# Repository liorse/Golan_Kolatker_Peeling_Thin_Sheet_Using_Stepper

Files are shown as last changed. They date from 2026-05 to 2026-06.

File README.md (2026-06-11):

# Peeling Thin Sheet Using Stepper Motor — ESP32 Controller

Firmware for an automated thin-sheet peeling machine driven by a NEMA 17 stepper motor and controlled via a Wemos D1 R32 (ESP32).

---

## Table of Contents

- [Overview](#overview)
- [Hardware](#hardware)
- [Wiring](#wiring)
- [Software Dependencies](#software-dependencies)
- [Installation](#installation)
- [Configuration](#configuration)
- [Serial Command Interface](#serial-command-interface)
- [Serial Output](#serial-output)
- [State Machine](#state-machine)

---

## Overview

This firmware:
- Controls a NEMA 17 stepper motor through a DM542T driver to drive a peeling stage.
- Drives a 240×320 ST7789 TFT display (landscape) with a live status UI and settings menu.
- Supports 4 physical buttons for UI navigation, start/stop, homing, and calibration.
- Reads two independent limit switches (home end and far end).
- Reads temperature via a MAX31856 thermocouple amplifier (K-type) and drives a heater MOSFET with a PID controller.
- Connects to an existing Wi-Fi network (station mode) and hosts a WebSocket-based status/control UI on port 80.
- Exposes a serial command interface (115 200 baud) for external software control via a USB-serial bridge.
- Emits a JSON heartbeat every 100 ms so a host application can monitor position, state, and temperature in real time.

---

## Hardware

| Component | Details |
|---|---|
| Microcontroller | Wemos D1 R32 (ESP32 dual-core, 240 MHz) |
| Stepper motor | NEMA 17 — rated 0.4 A |
| Stepper driver | DM542T (V4.0) — Leadshine digital driver, active-low ENA- |
| Display | 240×320 ST7789 TFT (VSPI, landscape rotation) |
| Limit switches | 2× microswitch — home end (X) and far end (Y) |
| Buttons | 4× push-button — A (start/stop), B (settings/home), X (increment/CAL), Y (decrement) |
| Thermocouple amplifier | Adafruit MAX31856 — K-type thermocouple, VSPI bus |
| Heater MOSFET | N-channel FET driven by 1 kHz PWM (LEDC) on GPIO 32 |

### Driver Configuration (DIP Switches)

| Switches | Function | Recommendation |
|---|---|---|
| SW1–SW3 | Peak output current | Match to motor rated current |
| SW4–SW6 | Microstep resolution | Match to firmware steps-per-rev setting (default 25600 steps/rev) |
| SW7 | Standby current reduction | ON = 50 % current at rest |
| SW8 | Pulse active edge | ON = rising edge (default) |

Refer to the DM542T datasheet for the exact SW1–SW3 current table.

---

## Wiring

### Stepper Driver

| ESP32 GPIO | Signal | Connected To |
|---|---|---|
| GPIO 26 | ENA+ | DM542T ENA+ (ENA- tied to GND) |
| GPIO 25 | DIR+ | DM542T DIR+ (DIR- tied to GND) |
| GPIO 27 | PUL+ | DM542T PUL+ (PUL- tied to GND) |

> The DM542T minimum HIGH is 3.5 V; ESP32 GPIO outputs 3.3 V — use a level shifter or voltage divider on step/dir/enable lines if the driver does not trigger reliably.

### Display (ST7789, VSPI)

| ESP32 GPIO | Signal |
|---|---|
| GPIO 18 | SPI SCK  (shared VSPI bus) |
| GPIO 23 | SPI MOSI (shared VSPI bus) |
| GPIO 19 | SPI MISO (shared VSPI bus) |
| GPIO  5 | TFT CS |
| GPIO 17 | TFT DC |
| GPIO  2 | TFT RST |
| GPIO 16 | TFT backlight |

### Thermocouple Amplifier (MAX31856, shares VSPI)

| ESP32 GPIO | Signal |
|---|---|
| GPIO 21 | MAX31856 CS |
| GPIO 22 | MAX31856 DRDY (data-ready, active-low) |

### Heater MOSFET

| ESP32 GPIO | Signal |
|---|---|
| GPIO 32 | Gate (1 kHz PWM via LEDC, 8-bit duty) |

### Buttons (active-low, internal pull-up)

| ESP32 GPIO | Button | Function |
|---|---|---|
| GPIO  4 | BTN_A | Start / stop; in settings: navigate up |
| GPIO 33 | BTN_B | Settings / home; in settings: navigate down / exit+save |
| GPIO 14 | BTN_X | In settings: increment (+) or trigger CAL |
| GPIO 12 | BTN_Y | In settings: decrement (−) |

### Limit Switches (active-low, internal pull-up)

| ESP32 GPIO | Switch | Triggers |
|---|---|---|
| GPIO 13 | Home / X end | HOMING → stop and zero position |
| GPIO 15 | Far / Y end  | CAL_RUNNING → record travel distance; PEELING/MOVING → safety abort |

---

## Software Dependencies

Install via the Arduino Library Manager before compiling:

| Library | Notes |
|---|---|
| **FastAccelStepper** | Hardware-timer step generation |
| **Adafruit ST7789** | TFT display driver |
| **Adafruit GFX** | Graphics primitives |
| **Adafruit MAX31856** | Thermocouple amplifier driver |
| **ESP Async WebServer** ≥ 3.3.x | Use the mathieucarbou fork — the me-no-dev fork has mbedtls API breakage with ESP32 core ≥ 3.x |
| **AsyncTCP** | Required by ESP Async WebServer |
| **ESPmDNS** | Bundled with the ESP32 core — no separate install needed |

---

## Installation

```bash
# Install ESP32 core (once)
arduino-cli core install esp32:esp32

# Compile
arduino-cli compile --fqbn esp32:esp32:d1_mini32 Peeling_Automation_Stepper_esp32/

# Upload (replace /dev/ttyUSB0 with the actual port)
# UploadSpeed=460800 is required — the CH340 on the D1 R32 drops at the default 921600
arduino-cli upload --fqbn esp32:esp32:d1_mini32:UploadSpeed=460800 --port /dev/ttyUSB0 Peeling_Automation_Stepper_esp32/

# Monitor serial output
arduino-cli monitor --port /dev/ttyUSB0 --config baudrate=115200
```

Add your Wi-Fi credentials in `Peeling_Automation_Stepper_esp32/wifi_credentials.h` before compiling.

### Serial Bridge (optional)

A Python serial bridge lets you control the instrument over USB without Wi-Fi:

```bash
cd serial_bridge
pip install -r requirements.txt
python serial_bridge.py          # auto-detect CH340
python serial_bridge.py /dev/ttyUSB0  # explicit port
```

Then open **http://localhost:8080** in any browser.

---

## Configuration

Key settings adjustable via the on-device settings menu (BTN_B → SETTINGS):

| Parameter | Description |
|---|---|
| Speed (µm/s) | Peel speed — adjustable at runtime via BTN_X/BTN_Y in settings |
| Angle (°) | Peeling arm half-angle θ — used for µm/step conversion |
| Start position (µm) | Distance from home to peel start point |
| CAL | Runs a full home→far-end traversal to measure travel distance |
| TEMP settings | PID setpoint, Kp/Ki/Kd, and controller on/off |
| Wait for temp | Hold peel at start position until temperature reaches setpoint |

Calibration (CAL) runs a full home→far-end traversal to measure travel distance automatically.

---

## Serial Command Interface

Connect at **115 200 baud**. Send a single character followed immediately by any numeric argument.

| Command | Argument | Description |
|---|---|---|
| `m` | `<int32>` | Move to absolute step position. Example: `m200000` |
| `s` | — | Stop motor immediately |
| `v` | `<int>` | Set motor max speed in Hz. Example: `v500` |
| `h` | `<0–255>` | Set heater duty cycle (blocked when PID control is active). Example: `h128` |
| `b` | `<A\|B\|X\|Y><1\|0>` | Virtual button press (1) or release (0). Example: `bA1` |

---

## Serial Output

Every **100 ms** the firmware emits a JSON heartbeat on Serial (and WebSocket). Key fields:

| Field | Description |
|---|---|
| `state` | State machine name: `"IDLE"`, `"MOVING"`, `"TO_START"`, `"WAIT_TEMP"`, `"PEELING"`, `"HOMING"`, `"SETTINGS"`, `"CAL_HOME"`, `"CAL_RUN"` |
| `position` | Current position in steps |
| `speed` | Current step rate (Hz) |
| `pos_um` | Current position in µm (peel distance) |
| `speed_um` | Current speed in µm/s |
| `speed_set` | Configured target speed in µm/s |
| `angle` | Configured arm half-angle (°) |
| `dist_xa_steps` | Calibrated X→A travel in steps (0 = not calibrated) |
| `dist_xa_um` | Calibrated X→A travel in µm |
| `peel_elapsed_ms` | Elapsed peel time in ms (non-zero during PEELING only) |
| `temp_c` | Thermocouple temperature in °C (`null` on fault) |
| `heater_duty` | Heater PWM duty 0–255 |
| `temp_setpoint` | Target temperature in °C |
| `temp_ctrl_active` | `true` when PID controller is running |
| `wait_for_temp` | `true` when peel waits for temperature to reach setpoint |
| `rssi` | Wi-Fi signal strength in dBm (0 = disconnected) |
| `clients` | Number of connected WebSocket clients |
| `ip` | Current Wi-Fi IP address string |

---

## State Machine

```
IDLE → [A, dist_xa > 0]           → MOVING_TO_START
IDLE → [A, dist_xa = 0]           → warning "RUN CAL FIRST" (stays IDLE)
IDLE → [B, pos = 0]               → SETTINGS
IDLE → [B, pos > 0]               → HOMING

MOVING_TO_START → [arrival + 100 ms, wait_for_temp = false] → PEELING
MOVING_TO_START → [arrival + 100 ms, wait_for_temp = true]  → WAITING_FOR_TEMP
WAITING_FOR_TEMP → [temp within ±2 °C of setpoint]          → PEELING

PEELING   → [motor reaches dist_xa or A or limit switch] → IDLE
HOMING    → [X limit switch]     → IDLE  (position := 0)
SETTINGS/CAL field → [X button]  → CAL_HOMING → CAL_RUNNING → IDLE (saves dist_xa)
Any moving state   → [A button]  → IDLE  (abort)

SETTINGS: A = navigate up, B = navigate down / exit+save, X = +/CAL/OPEN, Y = −
```

---

## Author

Lior Segev — Version 4.3.0-esp32, June 2026

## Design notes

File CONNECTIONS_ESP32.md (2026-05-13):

# ESP32 (Wemos D1 R32) — Wiring Reference

## Display — ST7789 via Pico Explorer Base header

The Pico Explorer Base display is permanently wired to the Pico's GPIO header.
Plug into those header pins directly; do **not** insert a Pico.

| Signal | ESP32 GPIO | Wemos D1 R32 label | Pico Explorer header pin | Pico GPIO |
|---|---:|---|:---:|---|
| DC | 17 | D4 | Pin 21 | GP16 |
| CS | 5 | D10 (SS) | Pin 22 | GP17 |
| SCK | 18 | D13 | Pin 24 | GP18 |
| MOSI | 23 | D11 | Pin 25 | GP19 |
| BL | 16 | D5 | Pin 26 | GP20 |
| GND | GND | GND | Pin 23 | GND |
| 3V3 | 3V3 | 3V3 | Pin 36 | 3V3\_OUT  |

> **RST** is not connected (firmware sets `TFT_RST = -1`). The display resets
> via the board's power-on rail.

> **Power**: with no Pico inserted, supply 3.3 V from the ESP32's 3V3 pin to
> Pico header **pin 36** to power the display circuitry.

---

## Buttons

All four Pico Explorer Base buttons are used. The X and Y buttons simulate the
home and far-end limit switches (microswitches) during bench testing.

| Function | ESP32 GPIO | Wemos D1 R32 label | Pico Explorer header pin | Pico GPIO |
|---|---:|---|:---:|---|
| BTN_A (start / stop / +) | 4 | A1 | Pin 16 | GP12 |
| BTN_B (settings / home / −) | 19 | D12 | Pin 17 | GP13 |
| BTN_X (home limit / simulate)  | 14 | IO14 | Pin 19 | GP14 |
| BTN_Y (far limit / simulate) | 12 | IO12 | Pin 20 | GP15 |

> All buttons are active-low. The ESP32 enables internal pull-ups so no
> external resistor is needed.

> **GPIO 21 (SDA) and GPIO 22 (SCL) are now free** for I2C peripherals.

> GPIO 12 is a strapping pin but safe to use here: the WROOM module's internal
> pull-down holds it LOW during reset (correct flash voltage), and the firmware's
> `INPUT_PULLUP` takes over after boot.

---

## Stepper Driver (DM542T)

| Signal | ESP32 GPIO | Wemos D1 R32 label | DM542T terminal |
|---|---|---|---|
| ENA+ | 26 | D2 | ENA+ |
| DIR+ | 25 | D3 | DIR+ |
| PUL+ | 27 | D6 | PUL+ |
| GND | GND | GND | ENA− / DIR− / PUL− (all three) |

> Active-high wiring: the − terminals are tied to GND, and the MCU drives the
> + terminals. ENA+ must go HIGH ≥ 200 ms before the first pulse (firmware
> uses 500 ms).

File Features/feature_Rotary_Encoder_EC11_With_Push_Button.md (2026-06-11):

# Feature: Rotary Encoder EC11 With Push Button

## Hardware
- **Component**: 360° Rotary Encoder EC11 with push button — bare 5-pin metal component (no breakout board)
- **Pin layout**:

```
3-pin side (encoder):        2-pin side (push button):
  [CLK]  [GND]  [DT]              [SW]  [SW]
    1      2      3                 4     5
```

- **Wiring**:
  - Pin 1 (CLK) → GPIO 14 (was BTN_X)
  - Pin 2 (middle/common) → GND
  - Pin 3 (DT) → GPIO 4 (was BTN_A)
  - Pin 4 or 5 (SW) → GPIO 33 (was BTN_B)
  - Pin 4 or 5 (SW, other) → GND
  - GPIO 12 (was BTN_Y) — left unused
  - **VCC not needed** — ESP32 INPUT_PULLUP provides pull-up; encoder shorts CLK/DT to GND

- **Identify pins**: use a multimeter in continuity mode — pressing the shaft should beep across the 2-pin side (push button). The 3-pin row is always the encoder.

## Compile-time switch

```cpp
#define ROTARY  1
#define BUTTONS 2
#define INPUT_MODE  ROTARY   // change to BUTTONS for 4-button mode
```

Place at the top of the `.ino` file. Comment/change `INPUT_MODE` to switch modes. No other code changes needed.

## Behaviour

### Main screen (IDLE)
- Rotate CW / CCW → move cyan highlight between **GO** and **SET/HOME** buttons (wraps)
- Push (SW) → activates the highlighted button
- Virtual buttons (WiFi / serial bridge) → bypass encoder, trigger actions directly (unchanged)

### Settings screen
- Button boxes are drawn **empty** (no labels) in rotary mode
- Two navigation modes:

  **Browse mode** (default on entry):
  - Rotate CW / CCW → move cyan highlight between settings fields (circular wrap)
  - Fields in order: SPEED → ANGLE → START → CAL → TEMP → WAIT_TEMP → EXIT
  - Push on a numeric field → enter **Edit mode**
  - Push on **CAL** → triggers calibration immediately (no edit mode)
  - Push on **WAIT_TEMP** → toggles value immediately (no edit mode)
  - Push on **EXIT** → saves settings and returns to main screen

  **Edit mode** (entered by pushing on a numeric field):
  - Rotate CW → increment value (1 click = 1 button-press step, same as existing X button)
  - Rotate CCW → decrement value (same as existing Y button)
  - Push → confirm value, return to Browse mode

### Temp sub-menu
Follows the exact same pattern as main settings:
- Browse mode: rotate between fields, push to enter edit or trigger action
- Fields: BACK (direct exit), SETPOINT, KP, KI, KD (all edit mode), STARTSTOP (direct toggle)

### Focus reset
Focus always resets to the **first field / button** (index 0) on every screen transition.

## Visual indicator
Focused button / field gets a **cyan background** with black text — distinct from idle (black bg) and pressed (white border) states.

## Encoder reading
- Polled in `loop()` — no interrupts
- **Software debounce**: ignore CLK transitions faster than 5 ms
- SW push button: existing 500 ms press/release logic, no long-press action

## What does NOT change
- The TFT display layout
- The WiFi web UI
- The serial bridge UI
- Virtual button protocol (`bA1`/`bA0` etc.)
- All existing logic when `INPUT_MODE BUTTONS` is selected

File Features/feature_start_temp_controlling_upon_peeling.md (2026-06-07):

# Feature: wait_for_temp — Start Peeling When Temperature is Reached

## Summary

Add a `wait_for_temp` yes/no setting. When enabled, pressing GO moves the motor to the
start position and then holds in a new `WAITING_FOR_TEMP` state until the thermocouple
reads within ±2 °C of the setpoint before starting the peel stroke.

## Agreed Design Decisions

| # | Question | Decision |
|---|---|---|
| 1 | Auto-activate temp control on GO? | No — user controls it manually; GO only auto-enables if `wait_for_temp=YES` and control is OFF |
| 2 | `wait_for_temp=YES` but `tempControlActive=OFF`? | Auto-enable temp control (reset PID), set `tempCtrlAutoEnabled=true`, proceed |
| 3 | Timeout if temp never arrives? | None — A-button abort works as today |
| 4 | State machine | New `WAITING_FOR_TEMP` state between `MOVING_TO_START` and `PEELING` |
| 5 | "Reached" threshold | ±2 °C — reuses existing `stable` definition |
| 6 | Settings placement | Top-level field after `FIELD_TEMP`: `SPEED → ANGLE → START → CAL → TEMP → WAIT_TEMP → [exit+save]` |
| 7 | UI during wait | State label = `"WAIT TEMP"` (yellow); right-column temp bar already shows progress |
| 8 | On peel end | Auto-disable heater only if `tempCtrlAutoEnabled`; leave on if user enabled it manually |

## Implementation Checklist

- [x] `AppState` enum: add `WAITING_FOR_TEMP`
- [x] `SettingsField` enum: add `FIELD_WAIT_TEMP`
- [x] New globals: `bool waitForTemp`, `bool tempCtrlAutoEnabled`
- [x] `cycleSettingsField()`: insert `FIELD_WAIT_TEMP` before exit
- [x] Button handler `SETTINGS`: `X=YES`, `Y=NO` for `FIELD_WAIT_TEMP`
- [x] `startMoveToStart()`: if `waitForTemp && !tempControlActive` → auto-enable PID + set flag
- [x] `MOVING_TO_START` case: on motor stop, go to `WAITING_FOR_TEMP` instead of calling `startPeeling()`
- [x] New `WAITING_FOR_TEMP` case: check ±2 °C → call `startPeeling()`
- [x] `abortAndIdle()` + `PEELING → IDLE`: if `tempCtrlAutoEnabled`, turn heater off + clear flag
- [x] EEPROM: bump magic `PEL5 → PEL6`, add `waitForTemp` field
- [x] Settings display: render `FIELD_WAIT_TEMP` row as `"WAIT:YES"` / `"WAIT:NO"`
- [x] Heartbeat JSON: add `"wait_for_temp"` bool field
- [x] Web UI (PROGMEM + `serial_bridge/index.html`): add `WAIT_TEMP` to `STATE_COL` (yellow), render state label

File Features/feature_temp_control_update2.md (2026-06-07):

# Temperature Control Implementation

## PID Parameters (from analysis)

```
KP = 60.0
KI = 0.15
KD = 900.0
PID_BAND = 4.0°C   # Bang-bang outside, PID inside
```

## Control Algorithm

```python
def compute_heater_pwm(current_temp, setpoint, dt):
    error = setpoint - current_temp

    # 1. Safety cutoffs (skip PID entirely)
    if isnan(current_temp) or current_temp >= 120.0:
        return 0.0

    # 2. Bang-Bang outside active zone
    if error > PID_BAND:
        return 100.0   # Full power for fast warmup
    if error < -PID_BAND:
        return 0.0     # Turn off if over-temperature

    # 3. PID within the zone
    P_term = KP * error

    integral_stored += error * dt
    integral_stored = clamp(integral_stored, -50/KI, +50/KI)  # I-term contribution ±50%
    I_term = KI * integral_stored

    raw_derivative = (error - last_error) / dt
    filtered_derivative = 0.7 * filtered_derivative + 0.3 * raw_derivative  # low-pass
    D_term = KD * filtered_derivative

    last_error = error
    output = P_term + I_term + D_term
    return clamp(output, 0.0, 100.0)
```

## Design Decisions

| # | Decision |
|---|---|
| 1 | PID runs inside the temp-read `if` block, right after `lastTempC` is set, using `dt = (nowMs - lastPidRunMs) / 1000.0f` |
| 2 | PID writes `heaterDuty` directly (0–255); `h` serial command is blocked with log when `tempControlActive == true` |
| 3 | `integral_stored`, `last_error`, `filteredDerivative` reset to 0 only on false→true activation |
| 4 | Heater zeroed immediately on true→false deactivation |
| 5 | `isnan(lastTempC)` → force off; `lastTempC >= 120.0°C` → force off; both skip PID |
| 6 | I-term clamped to ±50 (integral_stored clamped to `±50/ki`) |
| 7 | Derivative low-pass filtered: `filteredDerivative = 0.7f * prev + 0.3f * raw` |
| 8 | `tempControlActive` always boots `false` regardless of EEPROM |
| 9 | First tick after activation skips computation, just records `lastPidRunMs` |

## New State Variables

```cpp
float         pidIntegral        = 0.0f;
float         pidLastError        = 0.0f;
float         pidFilteredDeriv    = 0.0f;
unsigned long lastPidRunMs        = 0;
```

All reset to 0 on activation; `lastPidRunMs = 0` triggers first-tick skip.

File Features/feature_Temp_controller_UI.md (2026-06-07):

# Temperature Controller UI

## Resolved Design (grilling session 2026-06-07)

---

## Layout

- Canvas expands to **320×240** — the physical ST7789 display is already 320 wide; the firmware previously used only the centre 240 px.
- **Left column** (x 0–199, 200 px): existing stepper UI — run screen and settings screen, content unchanged except minor horizontal squeeze.
- **Right column** (x 200–319, 120 px): temperature bar, visible on **both** Run and Settings screens at all times.
- Vertical cyan divider separates the two columns.
- The existing `T: xx.x C` text row is **removed** from the left column (replaced by the right-column bar).

---

## Right Column — Temperature Bar

Top to bottom:

1. **Status indicator** (y ≈ 4)
   - `CTRL:OFF` in gray — loop not running
   - `CTRL: ON` blinking yellow at 500 ms — loop active, not yet stable
   - `STABLE` solid green — loop active and within ±2 °C of setpoint
2. **Power %** (y ≈ 18) — `PWR: xx%` (heater_duty / 255 × 100), cyan
3. **Vertical thermometer bar** (y 46–220, height 174 px)
   - Fills **bottom-to-top** (0 °C at bottom, 120 °C at top)
   - **Red** fill when not stable, **green** fill when stable
   - On fault (`temp_c = null`): entire bar red, shows `FLT`
4. **Setpoint line** — white horizontal line across the bar at the setpoint temperature, **always visible** regardless of control state
5. **Current temperature label** — floats to the right of the bar, near the top of the filled portion (`xx.x` format)

---

## Settings Screen

Main settings gains a 5th entry: **TEMP SETTINGS** (press `+`/`OPEN` to enter sub-menu).

### TEMP sub-menu fields (6 entries, navigated with A=up / B=down)

| # | Field | X button | Y button |
|---|---|---|---|
| 0 | `< BACK` | `BACK` — exits sub-menu | no-op |
| 1 | Setpoint | `+` / increment | `−` / decrement |
| 2 | Kp | `+` | `−` |
| 3 | Ki | `+` | `−` |
| 4 | Kd | `+` | `−` |
| 5 | Start/Stop | `ON` — enable control | `OFF` — disable control |

Pressing B on the last field (Start/Stop) exits the sub-menu back to main settings on the TEMP entry.

---

## Defaults, Ranges, and Steps

| Parameter | Default | Range | Step |
|---|---|---|---|
| Setpoint | 50 °C | 0–120 °C | 1 °C |
| Kp | 60 | 0–200 | 1 |
| Ki | 0.15 | 0–2.0 | 0.01 |
| Kd | 900 | 0–2000 | 10 |

PID rationale: slow thermal system with large thermal mass. Kp=60 avoids slamming. Ki=0.15 (Ti ≈ 400 s) is patient. Kd=900 (Td ≈ 15 s) applies early braking to prevent overshoot.

**Stability threshold**: ±2 °C (matches the planned bang-bang hysteresis; also tolerates MAX31856 noise floor).

---

## Firmware Additions (this step — control loop deferred)

| Item | Detail |
|---|---|
| New variables | `float tempSetpoint`, `bool tempControlActive`, `float kp`, `float ki`, `float kd` |
| EEPROM | Added to `SavedSettings`; magic bumped to `"PEL5"` |
| JSON heartbeat | `temp_setpoint`, `temp_ctrl_active`, `kp`, `ki`, `kd`, `in_temp_sub`, `temp_field` |
| Control loop | **Deferred to next step** |

---

## What is NOT in this step

- PID control loop execution (no output calculation, no integral/derivative accumulation)
- Automatic heater PWM from the loop (heater still driven by `h<duty>` serial command or manual override)

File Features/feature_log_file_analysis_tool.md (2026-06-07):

# Log File Analysis Tool

## Goal

A standalone HTML/JS tool for analysing peeling experiment CSV log files.

## Data Source

Log files are at `/home/liors/.config/peeling-controller/logs/`.

Two CSV schemas exist (tool handles both):
- **Older:** `timestamp, time_ms, pos_um, speed_um_s, temp_c, state`
- **Newer:** `timestamp, time_ms, pos_um, speed_um_s, temp_c, heater_duty, state`

## Design Decisions

| # | Decision | Choice |
|---|---|---|
| 1 | X-axis | Wall-clock timestamp (`timestamp` column) |
| 2 | Multi-file display | One chart, all selected runs overlaid with distinct colors |
| 3 | Duty cycle display | Text label in legend per run — e.g. "Run 14:10 — duty 255 (100%)" |
| 4 | File selection | Folder picker → checklist of CSVs to include |
| 5 | Chart library | Chart.js from CDN |
| 6 | Output location | `analysis_folder/analysis.html` |

## Behaviour

- User clicks "Open Folder", picks the logs folder
- A checklist of all `.csv` files appears (sorted newest-first)
- User checks the runs they want and clicks "Plot"
- A single temperature-vs-time chart renders with one colored line per run
- Each legend entry shows: filename stem + duty cycle if available (e.g. "14:10 — duty 100%")
- Files missing `heater_duty` show "duty n/a" in the legend

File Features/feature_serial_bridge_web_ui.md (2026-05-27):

# Feature: Serial-Bridge Web UI

## Request

Serve the same web UI that is currently served by the ESP32 over WiFi, but this time the
communication channel is the USB serial port.  The user runs a Python program on their
computer which:

1. Connects to the ESP32 over serial (USB/UART).
2. Serves the same webpage on `http://localhost:8080`.
3. Lets the user control the instrument through the identical web UI.

Parallel operation must be preserved: WiFi WebSocket and serial bridge can be active at the
same time.  Physical buttons + TFT display continue to function normally.

---

## Design Decisions (resolved)

| # | Topic | Decision |
|---|---|---|
| 1 | ESP32 firmware change | Add `bA1`/`bA0` serial commands for virtual button press/release injection.  Format: `b` + letter (`A`/`B`/`X`/`Y`) + `1` (press) or `0` (release).  Parsed with two `Serial.read()` calls after the `b` command character.  Keeps the entire state machine (settings, homing, CAL) in the firmware — full parity with WiFi mode. |
| 2 | Python stack | `asyncio` + `websockets` + `pyserial`.  Single Python file.  Two pip packages beyond stdlib. |
| 3 | Serial port selection | Auto-detect CH340 USB-serial adapter by VID `1A86` / PID `7523`.  If multiple CH340 ports are found, pick the first and print the full list as info.  User can override with a CLI positional argument: `python serial_bridge.py /dev/ttyUSB1`. |
| 4 | File layout | `serial_bridge/serial_bridge.py` + `serial_bridge/requirements.txt`. |
| 5 | HTTP / WS port | 8080 (default).  Can be overridden with a CLI argument. |
| 6 | HTML source of truth | `serial_bridge/index.html` — one canonical copy. |
| 7 | ESP32 HTML serving | Keep PROGMEM string in the sketch (reverted from LittleFS).  HTML is stored as `static const char HTML_PAGE[] PROGMEM = R"rawhtml(...)rawhtml"` in the `.ino` file.  Served via `req->send_P(200, "text/html", HTML_PAGE)`.  Python bridge reads `serial_bridge/index.html` directly from disk.  Both copies must be kept in sync when editing the UI. |
| 8 | LittleFS upload method | ~~Not needed — reverted to PROGMEM.~~  No separate filesystem flash step required. |
| 9 | Serial disconnection | Auto-reconnect.  Bridge polls for the CH340 port every 2 s.  Browser status line shows "SERIAL — reconnecting…" during the gap. |
| 10 | Button command format | `bA1` / `bA0` — three ASCII bytes.  `b` = button-inject command, next byte = button letter (`A`/`B`/`X`/`Y`), next byte = `1` (press) or `0` (release). |
| 11 | Transport indicator | Python injects `"transport":"serial"` into every JSON heartbeat it relays to the browser.  The shared `index.html` JavaScript checks for this field and shows a 🔌 SERIAL badge in the status line.  WiFi path is completely unchanged (field absent → badge hidden). |
| 12 | Listen address | `127.0.0.1` (localhost only).  Not exposed to the LAN by default. |
| 13 | Multi-CH340 behaviour | Pick the first found; print all detected ports as informational output.  User specifies a port explicitly via CLI arg to override. |

---

## Data Flow

```
ESP32 serial TX  →  Python asyncio reader  →  inject "transport":"serial"  →  ws.send(json)  →  browser
browser click    →  ws.recv({"btn":"A","action":"press"})  →  serial.write("bA1")  →  ESP32 onButtonPress()
```

The 100 ms JSON heartbeat that the firmware already emits on `Serial` is the sole state source;
the Python bridge passes it through verbatim (plus the injected `transport` field).

---

## Files to Create / Modify

| File | Action |
|---|---|
| `serial_bridge/serial_bridge.py` | **Create** — asyncio bridge |
| `serial_bridge/requirements.txt` | **Create** — `websockets`, `pyserial` |
| `serial_bridge/index.html` | **Create** — extracted from PROGMEM + SERIAL badge JS |
| ~~`Peeling_Automation_Stepper_esp32/data/index.html`~~ | ~~symlink to serial_bridge/index.html~~ — not needed (PROGMEM approach) |
| `Peeling_Automation_Stepper_esp32/Peeling_Automation_Stepper_esp32.ino` | **Modify** — (a) add `b` command to serial parser, (b) embed HTML as `PROGMEM` raw-string `HTML_PAGE`, served via `req->send_P()` |
| ~~`tools/upload_fs.py`~~ | ~~mklittlefs + esptool.py wrapper~~ — not needed (PROGMEM approach) |
| `CLAUDE.md` | **Update** — serial bridge usage; note about keeping PROGMEM + serial_bridge/index.html in sync |

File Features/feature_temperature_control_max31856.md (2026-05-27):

# Temperature Control — Future Feature

A future firmware update will add closed-loop temperature control of a heat pad.

## Hardware

- **Sensor**: CJMCU MAX31856 thermocouple amplifier with K-type thermocouple (SPI interface)
- **Actuator**: N-channel MOSFET module controlled via PWM (resistive heat pad load)

---

## Pin Conflict Resolution

GPIO 19 is currently `BTN_B` in firmware but is also declared as the VSPI MISO pin in
`SPI.begin(18, 19, 23, -1)`. The ST7789 display is write-only so this conflict was
harmless — until now. Wiring MAX31856 SDO to GPIO 19 would cause the sensor to fight the
button pull-up on every SPI read.

**Fix**: move BTN_B from GPIO 19 → GPIO 33 (one firmware line, one rewired breadboard wire).
GPIO 19 becomes a clean MISO. `SPI.begin()` is unchanged.

```cpp
// Peeling_Automation_Stepper_esp32.ino
#define BTN_B   33   // was 19
```

---

## MAX31856 Wiring

| MAX31856 Pin | Purpose | Connect to | Notes |
|---|---|---|---|
| VIN | Power input | ESP32 **3.3 V**  | Breakout has onboard regulator |
| 3Vo | Regulated 3.3 V output | **NC** | Output from breakout — leave unconnected |
| GND | Ground | **GND** | |
| SCK | SPI clock | **GPIO 18** | Shared VSPI SCK (display uses it too) |
| SDI | SPI data in (MOSI) | **GPIO 23** | Shared VSPI MOSI |
| SDO | SPI data out (MISO) | **GPIO 19** | Clean MISO now that BTN_B has moved |
| CS | Chip select (active-low) | **GPIO 21** | |
| DRDY | Data-ready interrupt | **GPIO 22** | New conversion ready ≈ every 143 ms |
| FLT | Fault output | **NC** | Read fault register via SPI instead |

---

## MOSFET PWM Wiring

| Signal | GPIO | Notes |
|---|---|---|
| PWM → MOSFET gate | **GPIO 32** | ESP32 LEDC, **1 kHz**, 8-bit duty |

---

## BTN_B Change Summary

| Signal | Old GPIO | New GPIO |
|---|---|---|
| BTN_B  | 19 | **33** |

---

## Remaining Free GPIOs After This Addition

| GPIO | Type | Status |
|---|---|---|
| 34 | Input-only  | Spare  |
| 35 | Input-only  | Spare  |
| 39 | Input-only  | Spare  |

---

## Future Firmware Implementation Notes

When implementing the temperature control loop:

1. **Library**: `Adafruit_MAX31856` — declare with `cs=21, drdy=22`
2. **PWM setup**:
   ```cpp
   ledcSetup(channel, 1000, 8);      // 1 kHz, 8-bit
   ledcAttachPin(32, channel);
   ledcWrite(channel, duty);          // 0–255
   ```
3. **EEPROM**: add `float target_temp_c` to `SavedSettings`; bump `EEPROM_MAGIC` to `"PEL5"`
4. **Settings field**: add `FIELD_TEMP` after `FIELD_CAL` in the `SettingsField` enum
5. **Safety**: on any MAX31856 fault (open/short thermocouple), immediately set PWM duty = 0
6. **Control**: start with bang-bang (on/off at setpoint ± hysteresis); upgrade to PID later if needed

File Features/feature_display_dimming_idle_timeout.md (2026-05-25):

# Display Dimming — Feature Spec

## Request
Dim the display after 20 seconds of idle activity (no external button pressed, no WiFi/WebSocket command received). Light it back up if a button is pressed or a WiFi command is sent.
Dim to 20% brightness.

## Decisions

| # | Question | Decision |
|---|---|---|
| 1 | Wake-on-press behaviour | **Wake + act** — the button press both restores brightness and executes its action (no double-press required) |
| 2 | Motor running = idle? | **Dim even during motor movement** — active PEELING/HOMING/MOVING states do not reset the timer |
| 3 | Serial commands | **Yes** — serial `m`, `s`, `v` commands reset the idle timer and wake the display |
| 4 | Timeout configurable? | **Hardcoded** `#define DIM_TIMEOUT_MS 20000` — not added to the Settings screen |
| 5 | Transition style | **Gradual fade** 255 → 51 over 1 second (linear, every loop iteration) |
| 6 | Wake transition | **Instant snap** to full brightness — no fade-up |

## Implementation Notes
- Brightness controlled via ESP32 LEDC PWM on GPIO 16 (TFT_BL), core 3.x pin-based API (`ledcAttach` / `ledcWrite`)
- `BL_FULL = 255`, `BL_DIM = 51` (20% of 255)
- Activity sources: physical buttons, WebSocket messages (via `wsActivityFlag` volatile bool), serial commands
- `wakeDisplay()` helper: snaps to full brightness + resets `lastActivityMs`
- Dim state machine: `displayFading` → linear interpolation → `displayDimmed`

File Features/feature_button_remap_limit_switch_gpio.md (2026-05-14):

# Corrections 9 — Button Remapping & Limit Switch GPIO

## Changes implemented

### New pin assignments
- `BTN_X` (GPIO 14) — now a UI button: **+** in settings, triggers CAL on CAL field, no-op outside settings
- `BTN_Y` (GPIO 12) — now a UI button: **−** in settings, no-op outside settings
- `LIMIT_SW` (GPIO 13) — **new**: both limit switches wired in parallel to this single pin (active-low, INPUT_PULLUP). Will be split to GPIO 32 and GPIO 33 in a future revision.

### Settings menu button mapping (new)

| Button | Action |
|---|---|
| A | Navigate **up** through fields (no-op on first field: SPEED) |
| B (short press) | Navigate **down**; exits and saves when leaving the last field (CAL) |
| X (press / hold) | **+** increment with auto-repeat; on CAL field → triggers calibration run |
| Y (press / hold) | **−** decrement with auto-repeat; no-op on CAL field |

### Outside settings
- X and Y are **no-ops** in all non-settings states.
- A and B behaviour in IDLE / moving states is unchanged.

### Display
- TFT button labels in settings: A=`UP`, B=`DOWN`, X=`+`/`CAL`, Y=`-`
- Hint line (`tap=NEXT  hold=-`) **removed** from both TFT and web UI.
- Web UI button labels are dynamic: show `+`/`-` in settings, `X`/`Y` otherwise.

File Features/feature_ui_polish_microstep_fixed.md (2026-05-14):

# Corrections 10 — UI Polish & Microstep Simplification

## Changes implemented

### 1. X and Y buttons hidden on main screen
- Outside the settings menu, the X and Y button boxes are erased (filled solid black, no border).
- They only appear when in settings, showing `+` / `CAL` and `-`.

### 2. UP / DOWN button font size
- In the settings menu, the A (`UP`) and B (`DOWN`) button labels now use text size 2, matching the size of `GO`, `STOP`, and `SET`/`HOME` on the main screen.

### 3. Microstep setting removed from UI; value fixed at 25600
- `FIELD_STEPS` removed from the `SettingsField` enum.
- Settings navigation is now: **Speed → Angle → Start → CAL → exit+save**.
- `steps_per_rev` is a compile-time constant (`25600`). It is no longer stored in or loaded from EEPROM.
- EEPROM magic bumped from `PEL3` → `PEL4`; existing saved settings are cleared on first boot. **Calibration must be re-run after flashing.**
- Settings field Y-positions spread slightly (24 px spacing instead of 22 px) now that there are only 4 rows.
- Web UI updated to match: 4-field loop, `settings_field===3` is CAL, X/Y boxes blank outside settings.

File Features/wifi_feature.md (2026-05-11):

# WiFi Feature — Design Specification

## Goal
Connect to the instrument via WiFi and get a browser UI that:
1. Pixel-perfectly replicates the physical 240×240 ST7789 display
2. Updates in real-time as the physical display changes
3. Exposes all four buttons (A, B, X, Y) as remotely actuatable controls

---

## Design Decisions

### WiFi Mode
- **Station mode** — ESP32 joins `WIS_Hotspot` (open network, no password)
- Credentials stored in `wifi_credentials.h` (gitignored), not hardcoded in `.ino`
- Boot is **non-blocking**: if the hotspot is unavailable the instrument works normally as a physical device
- Settings screen shows `"WiFi: connecting…"`, `"WiFi: 192.168.x.y"`, or `"WiFi: offline"` in real time
- mDNS advertises `http://peeling.local` for a permanent bookmark

### Real-Time Protocol
- **WebSocket** — ESP32 pushes a JSON heartbeat to all connected clients every 100 ms
- Library: `ESPAsyncWebServer` + `AsyncTCP`

### Browser UI
- **Pixel-perfect HTML canvas**, 240×240 internal coordinates, **CSS-scaled** to fit the viewport
- Both the **run screen and settings screen** are mirrored exactly
- No browser-only controls — strict mirror of the physical UI
- Canvas click/touch events on button regions send press/release WebSocket commands

### Button Semantics
- All four buttons (A, B, X, Y) are remotely actuatable
- **Press + Release events** — browser sends `{"btn":"A","action":"press"}` on mousedown/touchstart and `{"btn":"A","action":"release"}` on mouseup/touchend
- X and Y function as **limit switch simulators** — identical behavior to the physical microswitches
- Firmware injects virtual button state via `volatile bool virtualBtn[4]`, ORed with `digitalRead()` in the loop

### Concurrency
- `AsyncWebServer`/`AsyncTCP` run on core 0; `loop()` runs on core 1
- Shared variables protected with `portENTER_CRITICAL` / `portEXIT_CRITICAL` spinlock
- WebSocket callbacks write only to the virtual button booleans and a broadcast-pending flag; `loop()` owns all state machine logic

### Heartbeat Expansion
The 100 ms heartbeat JSON is expanded from ~70 bytes to ~200 bytes to support full canvas rendering:

```json
{
  "state": "PEELING",
  "position": 12345,
  "speed": 100,
  "pos_um": 11.58,
  "speed_um": 15.20,
  "speed_set": 15.0,
  "angle": 30,
  "spr": 1600,
  "dist_xa_steps": 478085,
  "dist_xa_um": 448.2,
  "start_pos_um": 0.0,
  "peel_elapsed_ms": 3200,
  "warning_active": false,
  "settings_field": 0,
  "btn": [false, false, false, false],
  "ip": "192.168.1.47"
}
```

### HTML Delivery
- Entire page (HTML + CSS + JS) stored as an **inline PROGMEM string** in the `.ino`
- No separate filesystem upload step required — same `arduino-cli compile/upload` as today

### IP Display
- IP address shown in the **settings screen** on the TFT (below the cal status line)
- Also accessible via mDNS at `http://peeling.local`

---

## Required Libraries
Install via Arduino Library Manager:
- `ESPAsyncWebServer` (by me-no-dev or mathieucarbou fork)
- `AsyncTCP` (by me-no-dev)
- `ESPmDNS` (built into ESP32 core — no install needed)

---

## Known Limitations
- If two browsers are open simultaneously, both can send button events. The firmware processes them in arrival order — no inter-client locking. Acceptable for single-lab use.
- The `enableMotor()` call blocks `loop()` for 500 ms (hardware DM542T requirement). During this window heartbeats are delayed; the browser will show a brief stale state. Harmless in practice.

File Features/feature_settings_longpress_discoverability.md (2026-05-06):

In the UI, when I press set the lower button shows the text next and the upper button shows in the specific situation + and in the cal option cal. all is fine. But, I want to alert the user that he can also press a long press on the lower button to function as a - and not just a next for a short press.

IMPLEMENTED: Two-pronged discoverability fix for the B button long-press decrement in Settings:

1. Button label — the lower-left button (B) now shows "NEXT/-" (textSize 1) instead of "NEXT" (textSize 2), communicating both the short-press (NEXT) and long-press (-) actions directly on the button.

2. Hint line — "tap=NEXT  hold=-" is drawn at y=56 (between the "SETTINGS" title and the first field) in cyan at textSize 1. It disappears when the CAL field is active (where long-press B has no effect) and reappears on any other field.

Implementation: `drawButtonBox` gained an optional `sz` parameter (default 2) for textSize. `updateButtons` passes `bSz=1` and label `"NEXT/-"` for the B button in SETTINGS. A new `drawSettingsHint(fieldIdx)` helper draws or clears the hint line; called from `updateSettingsContent` on first draw and on every field change.

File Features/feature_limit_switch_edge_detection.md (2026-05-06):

there is a problem with the limit switches.

the problems description is as follow:

when the instrument returns home and the home limit switch is turned on. it remains turned until the motor moves out of home. but the motor can't move because it is on. 

the solution is to detect a rising or a falling edge, whatever is needed and not query the current limit switch position.

FIXED: replaced level-detection with falling-edge + 2 ms debounce for the safety abort
in MOVING / MOVING_TO_START / PEELING states. The fix applies symmetrically to both the
home (X) and far-end (Y) limit switches.

Implementation: `limitXPrev`/`limitYPrev` track the switch state from the previous loop
iteration; `limitXStableAt`/`limitYStableAt` record the timestamp of the falling edge.
The abort fires only when the switch has been continuously LOW for ≥ 2 ms AND was HIGH
on the preceding iteration (`xNewPress` / `yNewPress` flags). Once fired the timer is
cleared so the abort does not re-trigger for the same press.

HOMING and CAL_HOMING states retain level-detection (no change): those states are only
entered when the motor is away from the home switch, so a LOW reading always means a
fresh contact.

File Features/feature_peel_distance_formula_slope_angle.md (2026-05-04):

I finally have the formula for the real distance travelled upon one pulse for one step for the stepper motor.

real_distance_travelled = 2 * (distance travelled in one step) * cos( slope angle/2)

slope angle is given deg. this is the angle the user inputs in the settins menu.

calculate speed and distance according to this formula

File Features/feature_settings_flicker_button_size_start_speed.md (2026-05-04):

1. when going in to setting and trying to change values the display flickers. can you fix that?
   FIXED: replaced full-area fillRect+redraw with targeted per-row updates. Only the active
   field row is redrawn on value changes; only the old and new rows update on field transitions.
   Title and cal status are drawn once on entry.

2. buttons text are too small. can you make them as large as POS text for example
   FIXED: BTN_W widened 28→52 px; drawButtonBox switched to textSize 2 (12×16 px per char)
   with corrected centering math.

3. when going to start please use the same speed as you do for homing the device.
   FIXED: startMoveToStart() now uses CAL_SPEED_HZ (1067 Hz ≈ 1 mm/s) instead of 100 Hz.

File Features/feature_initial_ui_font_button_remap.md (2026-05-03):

in the main screen the fonts are too small. make them as large as the font in POS:0.0

there is a mix up with the buttons. make buttons X and Y the microswitch button simulations. they cannot take part in the UI manipulation.

The calibration should be run in a relative high speed 5mm/sec is acceptable.

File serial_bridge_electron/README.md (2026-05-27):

# Peeling Controller — Electron App

Node.js / Electron port of `serial_bridge.py`.  
Double-click the app → serial bridge starts → window opens automatically.

## Development

**Requires Node ≥ 16** (use nvm if your system node is older):

```bash
# If you have nvm:
nvm use 17      # or any ≥ 16

npm install
npm start                         # open app window
npm start -- /dev/ttyUSB0        # specify serial port (Linux)
npm start -- COM3                 # specify serial port (Windows)
```

The first `npm install` runs `electron-rebuild` automatically to compile
`serialport`'s native bindings against the bundled Electron Node version.

## Bridge-only (no Electron window)

```bash
node bridge.js                    # auto-detect CH340
node bridge.js /dev/ttyUSB0      # explicit port
node bridge.js --http-port 9090  # custom HTTP port
```

Then open **http://localhost:8080** in any browser — same as the Python bridge.

## Build distributable

```bash
npm run dist:linux   # → dist/  (.AppImage + .deb, x64)
npm run dist:win     # → dist/  (.exe installer + portable, x64)
```

**Cross-compilation note**: `serialport` uses native C++ bindings.  
To build the Windows `.exe` you must run `npm run dist:win` **on Windows**.  
To build the Linux `.AppImage` run `npm run dist:linux` **on Linux**.

Experiment logs (CSV) are written to:
- **Development**: `serial_bridge_electron/logs/`
- **Packaged app**: `%APPDATA%\peeling-controller\logs\` (Windows)  
  or `~/.config/peeling-controller/logs/` (Linux)

## How it differs from the Python bridge

| | Python bridge | Electron app |
|---|---|---|
| Runtime needed | Python 3.8 + pip | none (self-contained) |
| Opens browser | manually | automatic window |
| Log location | `serial_bridge/logs/` | user data dir (packaged) |
| Platforms | any with Python | Windows, Linux |

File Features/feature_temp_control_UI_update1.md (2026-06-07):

# Temperature Column UI Update 1

## Original Problems

1. Flickering in the temp part of the display
2. Residual lines when changing setpoint
3. Setpoint line flickering
4. Bar too small; requested bigger and centered
5. Show setpoint temperature above the setpoint line
6. Make temp area as small as possible (more room for peeling window)
7. Fonts in the temp column too small

## Design Decisions (resolved via grilling)

### Flicker fix (items 1, 3)
**Decision:** dirty-state tracking — `updateTempColumn()` now stores `prevFillH`,
`prevSpY`, `prevBarColor`, `prevHeaterDuty`, `prevCtrlStatus`, `prevTempDrawn`,
`prevTempLabelY`, and `prevFault` as static locals. Each section only repaints
pixels when the relevant value changes.

### Residual setpoint lines (item 2)
**Decision:** track `prevSpY`. On setpoint change: erase old line at full width
(`TBAR_X - 4`, length `TBAR_W + 8` — includes the 4 px overhang that caused the
ghost lines), clear the entire label column (`fillRect` from `labelX` to screen
right), then redraw the new line and label. Force bar redraw to restore any fill
pixels overwritten by the erase.

### Bar size and position (item 4)
**Decision:** `TBAR_W` widened from 22 → 40 px. `TBAR_X` shifted from 205 → 209
to center the bar+label block within the 119 px right column
(margin = (119 − 103) / 2 = 8 px; 103 = 40 bar + 3 gap + 60 label).

### Item 6 — column width
**Decision:** keep floating temp label to the right of the bar (user preference).
Column width unchanged at 119 px. The wider bar (40 px) plus size-2 label
consumes 103 px, leaving 8 px margin each side — visually centered.

### Setpoint label (item 5)
**Decision:** show setpoint value (e.g. `"50C"`) in size-2 to the right of the
bar at `y = spY − 17` (one text-row above the setpoint line), clamped to
`[TBAR_TOP, TBAR_BOT − 16]`.

### Temp label vs setpoint label collision
When temperature approaches setpoint the two labels would overlap. Resolution:
if `|tempLabelY − spY| < 12`, push the temp label to `spY + 2` (just below the
setpoint line). Both labels remain visible; setpoint label stays above the line.

### Fonts (item 7)
**Decision:** `setTextSize(2)` for all right-column text (status, PWR%, temp
label, setpoint label). All text fits within the 119 px column at size-2.

## Files Changed

- `Peeling_Automation_Stepper_esp32/Peeling_Automation_Stepper_esp32.ino`
  - `#define TBAR_X 209` (was 205)
  - `#define TBAR_W  40` (was 22)
  - `updateTempColumn()` fully rewritten with dirty-state tracking
  - JS constants in PROGMEM string updated: `TBAR_X=209,TBAR_W=40`
- `serial_bridge/index.html`
  - JS constants updated: `TBAR_X=209,TBAR_W=40`

---

## Follow-up Session — Bug Fixes & Layout Polish

### Bug: Black screen after exiting settings

**Root cause:** `updateRunContent()` uses static `prev*` variables to skip unchanged
rows. When B navigates from FIELD_TEMP back to IDLE, `clearContent()` wipes the left
panel, but all statics still matched the old IDLE values → every `strcmp`/`!=` check
passed and nothing was redrawn.

**Fix:** Added global `bool runScreenDirty = false;`. In the 100 ms heartbeat, when
the screen transitions settings → run, set `runScreenDirty = true`. At the top of
`updateRunContent()`, if the flag is set, reset all statics to their sentinel values
and clear the flag — forcing a full redraw in the same tick.

### Bug: Flicker and erasure of vertical divider during run screen

**Root cause:** Two rows overflowed past `LEFT_W = 200 px` into the right temperature
column on every heartbeat tick:

| Row | Start x | Chars × 12 px | End x | Overflow |
|-----|---|---|---|---|
| State label | 0 | 20 × 12 = 240 | 240 | 40 px |
| POS / warning | 6 | 19 × 12 = 228 | 234 | 34 px |

The overflow overwrote the vertical divider line and portions of the temperature bar.
Because `updateTempColumn()` uses dirty-state tracking (not a full redraw), the damage
persisted until the next partial repaint, causing visible flicker and ghosting.

**Fix:**
- State label reduced to **16 chars** centred in the left column
  (`16 × 12 = 192 px` from x = `(200 − 192) / 2 = 4`; ends at x = 196).
- POS normal row: `"um      "` (8 chars) → `"um   "` (5 chars);
  total 4 + 7 + 5 = 16 chars from x = 6; ends at x = 198.
- POS warning row: `"!CAL FIRST!        "` (19 chars) → `"!CAL FIRST!     "` (16 chars);
  from x = 6, ends at x = 198.
- `prevSb` buffer shrunk from 22 → 18 bytes to match.

### Layout: Centred state label

The 16-char state string is now drawn starting at x = 4 (formula:
`(LEFT_W − 16 × 12) / 2 = 4`) instead of x = 0. Both firmware and JS updated.

### Layout: Centred WiFi icon and client count

**Problem:** WiFi icon was at `cx = 120`, client count at x = 136. With 2-digit counts
the text reached x = 148, overlapping the top-right button box (x = 145..197).

**Decision:** Move icon to `cx = 100` — the geometric centre of the 90 px gap between
the two top button boxes (left button ends at x = 55, right button starts at x = 145;
centre = (55 + 145) / 2 = 100).

| Element | Old | New |
|---|-----|-----|
| WiFi icon centre | cx = 120 | cx = 100 |
| Icon span | x = 106..134 | x = 86..114 |
| Client count x | 136 | 116 |
| Client count max (2 digits) | 148 (clips button) | 128 (clear of button at 145) |

Both firmware (`drawWifiIcon()` + heartbeat client-count draw) and JS updated.

## All Files Changed (cumulative)

- `Peeling_Automation_Stepper_esp32/Peeling_Automation_Stepper_esp32.ino`
  - `#define TBAR_X 209`, `#define TBAR_W 40`
  - `updateTempColumn()` — dirty-state tracking
  - `updateRunContent()` — `runScreenDirty` reset, 16-char state label at x=4,
    shortened POS/warning rows, `prevSb[18]`
  - `drawWifiIcon()` — `cx = 100`
  - Heartbeat client-count draw — `fillRect(114,...)`, `setCursor(116,...)`
  - Global `bool runScreenDirty`
  - JS in PROGMEM — `cx=100`, client count at x=116, state label 16 chars at x=4,
    POS/warning rows shortened to 16 chars
- `serial_bridge/index.html` — same JS changes as PROGMEM copy
- `serial_bridge_electron/index.html` — same JS changes (WiFi icon cx=100,
  client count at x=116, state label 16 chars at x=4, POS/warning rows shortened)

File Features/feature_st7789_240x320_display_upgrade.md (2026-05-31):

## New 2.8" 240×320 ST7789 display — decisions

**Goal:** swap in the 2.8" 240×320 RGB display (same ST7789 interface), rotate it CW 90°, and fix the inverted colors.

### Decisions

| Question | Decision |
|---|---|
| Orientation after rotation | Landscape (320 wide × 240 tall) |
| Connector edge in landscape | Right edge → `setRotation(3)` |
| Layout changes | None for now; content stays in left 240×240 region |
| Panel offset | No offset — start with `tft.init(240, 320)` and check |

### Color inversion explanation

The ST7789 chip has a display-inversion register (INVON/INVOFF). Different panel manufacturers ship with it in different states. The old 240×240 module had it off; the new 240×320 module has it on, causing black↔white swap. Fix: `tft.invertDisplay(false)` after `tft.init()` — the Adafruit ST7789 `init()` already calls `invertDisplay(true)` internally, so we override it with `false`.

### Code changes (setup())

```cpp
// Before
tft.init(240, 240);
tft.setRotation(2);

// After
tft.init(240, 320);
tft.setRotation(3);
tft.invertDisplay(false);
```

### Future work
- Extend layout to use the full 320px width (extra 80px currently blank on the right).

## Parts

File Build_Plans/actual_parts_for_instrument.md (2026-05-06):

# Peeling Instrument — Build Specification

## Original Requirements
this is an interesting option for a display:
https://www.adafruit.com/product/3787

also a good option:
https://www.adafruit.com/product/4311

1. A professional-looking box containing the power supply, Pico W (WiFi), and stepper driver.
2. Box inputs: power button (24V rail + 5V Pico), two UI buttons, USB connector for firmware updates, 220V socket.
3. Box outputs: stepper motor connector, display.
4. Minimal soldering.
5. Power the Pico from the 24V DC rail (no battery).

---

## Decisions Made

| Topic | Decision |
|---|---|
| MCU | Raspberry Pi Pico W (RP2040 + WiFi) — NOT Pico 2W |
| Pico power | TSR 1-2450 buck regulator (24V → 5V, SIP-3), feeds VSYS pin |
| Pico programming | Panel-mount micro-USB on rear; coexists with VSYS power (internal OR-diode) |
| WiFi | Status monitoring + remote control (firmware TBD separately) |
| Enclosure | Hammond 1455Q2202 — 220×125×52mm aluminum body, plastic end panels (RF-transparent for Pico W WiFi) |
| AC switching | Illuminated rocker switch on front panel (mains-rated, 250V/10A) |
| IEC inlet | Rear panel, IEC C14 + integrated fuse holder, 1A T slow-blow fuse |
| Display | Waveshare Pico-ResTouch-LCD-3.5 (ILI9488, 480×320, ~73×49mm active area) — plugs directly onto Pico 40-pin header via SPI1 (GP8–GP13, GP16–GP17); **firmware pin reassignment + driver change required (not yet done)** |
| UI buttons | 2× Gateron KS-33 LP Brown (tactile) + low-profile MX keycaps, 14×14mm plate cutout, snap into 1.5mm aluminum panel |
| Button illumination | State-controlled via GPIO 0 (B-LED) and GPIO 1 (Y-LED) through 2N2222 transistors (reassigned from GP6/7 which conflict with Waveshare) |
| AC switching | Rear panel — illuminated rocker switch (mains-rated, 250V/10A); moved from front panel to accommodate 3.5" display width |
| Stepper output | GX16-4 aviation connector, 4-pin, female panel-mount on rear |
| Motor cable end | GX16-4 male plug (A+/A−/B+/B−) |
| Labels | Front Panel Express custom-printed aluminum panel |
| Display bezel | 3D-printed (design after ST7789 module arrives and PCB is measured) |
| E-stop | None |

---

## Complete Parts List

### Enclosure
| Part | MPN | Spec | Source | ~Cost |
|---|---|---|---|---|
| [Hammond 1455Q2202](https://www.hammfg.com/part/1455Q2202) | 1455Q2202 | 220×125×52mm, plastic end panels (WiFi-transparent) | [Mouser](https://www.mouser.com/ProductDetail/Hammond-Manufacturing/1455Q2202?qs=CUcEH/sN5tIHhQeXecWocA%3D%3D) / [DigiKey](https://www.digikey.com/en/products/detail/hammond-manufacturing/1455Q2202/2094863) | ~$35 |

### Power
| Part | MPN | Spec | Source | ~Cost |
|---|---|---|---|---|
| [Mean Well LRS-75-24](https://www.meanwell.com/productPdf.aspx?i=403) | LRS-75-24 | 24V / 3.2A, 75W | (already owned) — [DigiKey](https://www.digikey.com/en/products/detail/mean-well-usa-inc/LRS-75-24/7705055) / [Amazon](https://www.amazon.com/MeanWell-LRS-75-24-Power-Supply-75W/dp/B077B3X7S3) | — |
| [TSR 1-2450](https://www.tracopower.com/model/tsr-1-2450) | TSR 1-2450 | 24V → 5V / 1A, SIP-3 | [Mouser](https://www.mouser.com/ProductDetail/TRACO-Power/TSR-1-2450?qs=ckJk83FOD0XFKqda0Mzkgw%3D%3D) / [DigiKey](https://www.digikey.ca/en/products/detail/traco-power/TSR-1-2450/9383780) | $6 |
| [Schurter 4301.1400](https://www.schurter.com/en/products-and-solutions/components/connectors/power-entry-modules) | 4301.1400 | IEC C14 + fuse holder, panel-mount | [Mouser](https://www.mouser.com/c/connectors/power-entry-connectors/?m=Schurter) | $5 |
| Fuse T1A 5×20mm | — | 1A slow-blow | Any (DigiKey, Mouser, Amazon) | $1 |

### Front Panel
| Part | MPN | Spec | Source | ~Cost |
|---|---|---|---|---|
| [KCD3 rocker switch](https://www.aliexpress.com/w/wholesale-kcd3-rocker-switch.html) | KCD3 | 22×30mm cutout, 250V/10A, illuminated | [AliExpress](https://www.aliexpress.com/w/wholesale-kcd3-rocker-switch.html) | $3 |
| [Waveshare Pico-ResTouch-LCD-3.5](https://www.waveshare.com/pico-restouch-lcd-3.5.htm) | Pico-ResTouch-LCD-3.5 | ILI9488, 480×320, ~73×49mm active area, plug-on Pico board (SPI1 GP8–GP13, GP16–GP17) | [Waveshare](https://www.waveshare.com/pico-restouch-lcd-3.5.htm) | ~$25 |
| [Gateron KS-33 LP 2.0 Brown (35pcs)](https://www.gateron.com/products/gateron-ks-33-low-profile-switch-set) | KS-33 Brown | Low-profile tactile, 14×14mm plate cutout, SMD LED slot, 1.5mm plate snap-in | [Gateron](https://www.gateron.com/products/gateron-ks-33-low-profile-switch-set) / [Amazon](https://www.amazon.com/GATERON-Switches-Pre-lubed-Mechanical-Keyboard/dp/B0BZYHJ9XB) | ~$15 (35pcs, need 2) |
| Low-profile MX keycaps 1U blank (×2) | — (generic) | LP MX stem, fits KS-33 — e.g. Nuphy or Keychron LP caps | [Amazon](https://www.amazon.com/s?k=low+profile+mx+keycap+1u+blank) / [Keychron](https://www.keychron.com) | ~$5 |
| [Front Panel Express panel](https://www.frontpanelexpress.com/) | — (custom) | 122×78mm, **1.5mm aluminum** (required for MX snap-in mount) | [frontpanelexpress.com](https://www.frontpanelexpress.com/) | ~$40 |

### Rear Panel
| Part | MPN | Spec | Source | ~Cost |
|---|---|---|---|---|
| [GX16-4 female panel-mount](https://www.aliexpress.com/item/32830722292.html) | GX16-4 | 4-pin aviation socket | [AliExpress](https://www.aliexpress.com/item/32830722292.html) | $2 |
| [GX16-4 male cable-end](https://www.aliexpress.com/item/32830722292.html) | GX16-4 | 4-pin aviation plug (for motor cable) | [AliExpress](https://www.aliexpress.com/item/32830722292.html) | $2 |
| [Panel-mount micro-USB](https://www.aliexpress.com/w/wholesale-micro-usb-panel-mount.html) | — (generic) | Female, solder terminals | [AliExpress](https://www.aliexpress.com/w/wholesale-micro-usb-panel-mount.html) | $4 |

### MCU
| Part | MPN | Spec | Source | ~Cost |
|---|---|---|---|---|
| [Raspberry Pi Pico W](https://www.raspberrypi.com/products/raspberry-pi-pico/) | SC0918 | RP2040, 2.4GHz WiFi, micro-USB | [Raspberry Pi](https://www.raspberrypi.com/products/raspberry-pi-pico/) / [Adafruit](https://www.adafruit.com/product/5526) / [DigiKey](https://www.digikey.com/en/products/detail/raspberry-pi/SC0918/16608263) | $6 |

### Internal Electronics
| Part | MPN | Qty | Source | ~Cost |
|---|---|---|---|---|
| 2N2222 NPN transistor (TO-92) | 2N2222A | 2 | Any | <$1 |
| 1kΩ resistor 1/4W | — (generic) | 2 | Any | <$1 |
| Perfboard strip | — (generic) | 1 small | Any | $1 |

### Wiring & Connectors
| Item | Notes |
|---|---|
| 1.5mm² mains wire (L/N/PE) | Brown, blue, green-yellow — IEC inlet → rocker switch → PSU |
| Bootlace ferrules 1.5mm² | Crimp on all mains wire ends |
| 0.5mm² hookup wire, assorted | DC signals and LED wiring |
| Dupont female-to-female cables 20cm | Pico GPIO → display (7 wires) and GPIO → buttons |
| Short micro-B to micro-B USB cable | Internal: panel-mount USB socket → Pico W USB port |

---

## Front Panel Layout (122mm × 78mm)

```
|←13→|←14→|←8→|←────73────→|←14→|
      BTN-B       DISPLAY
      BTN-Y
```

PWR rocker is on the rear panel (3.5" display fills available front width).
All items vertically centered on the 78mm face.

---

## Internal Wiring Summary (minimal soldering)

| Connection | Method | Solder joints |
|---|---|---|
| 220V inlet → front rocker → PSU | Ferrule-crimped wire | 0 |
| PSU 24V → DM542T power | Screw terminals both ends | 0 |
| DM542T step/dir/ena → Pico GPIO | DM542T screw terminals + Dupont on Pico header | 0 |
| PSU 24V → TSR 1-2450 → Pico VSYS | Short wires, SIP-3 on perfboard | ~3 |
| Pico GPIO → display | Dupont female-to-female harness (7 wires) | 0 |
| Pico GPIO → buttons (signal) | Dupont female per button | 0 |
| Pico GPIO 6/7 → 2N2222 → button LEDs | Transistor circuit on perfboard | ~4 |
| DM542T output → GX16-4 panel socket | 4 wires soldered to GX16-4 | 4 |

**Total soldering: ~11 joints.**

---

## Firmware Changes Required

The Waveshare Pico-ResTouch-LCD-3.5 occupies GP8–GP13 and GP15–GP17 (display + touch). Several of these conflict with the current firmware. Required changes before hardware assembly:

| Change | Current | New |
|---|---|---|
| Display driver | `Adafruit_ST7789` | Waveshare ILI9488 library |
| SPI bus | SPI0 (GP18/19) | SPI1 (GP10/11, internal to Waveshare board) |
| Screen resolution | 240×240 | 480×320 + landscape UI layout |
| BTN_A pin | GP12 | **GP6** |
| BTN_B pin | GP13 | **GP7** |
| BTN_Y limit pin | GP15 | **GP2** |
| B-LED pin | GP6 | **GP0** |
| Y-LED pin | GP7 | **GP1** |

BTN_X (GP14) and stepper pins (GP3/4/5) are unaffected.
Estimated scope: ~20 lines for pin reassignment + display driver swap + UI layout recalculation.

---

## Action Items (ordered)

1. Order all parts except Front Panel Express panel and display bezel.
2. Receive ST7789 module → measure PCB dimensions.
3. Design and print display bezel.
4. Design Front Panel Express file (122×78mm) → order panel.
5. Wire internal components.
6. Add GPIO 6/7 LED control to firmware.

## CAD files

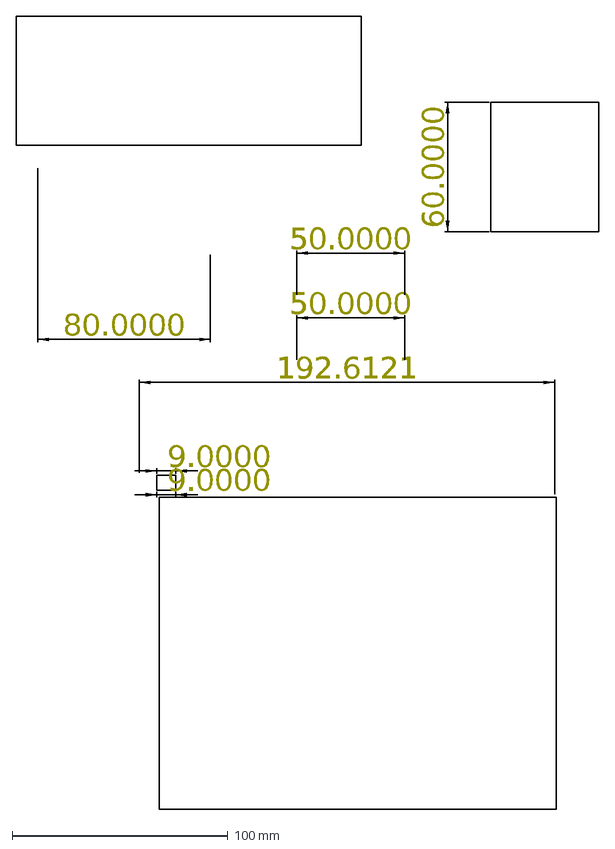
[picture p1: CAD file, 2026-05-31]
schematic_design/schematic_design.dxf
192.6121
9.0000
50.0000
80.0000
60.0000

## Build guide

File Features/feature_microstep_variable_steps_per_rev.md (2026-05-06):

I want to add another complexity. As of now I set the stepper driver to microstep at 1600 pulses per revolution. I want this to be a variable that can get the following values (200, 400, 800, 1600, 3200, 6400, 12800, 25600)

at the default (no microstepping) it takes 200 steps for a full revolution. i.e every step 1.8 degrees. in a full revolution the stepper moves linearly 1.5 mm ( that is before taking the angle into consideration - not actual peel transversale) -> in 1600 steps that's 1500um/1600 = 0.9375 um per step. 
I want you to recalculate the step size for the specific number of steps i choose for the motor. 

can you add this steps/revolution parameter to UI?

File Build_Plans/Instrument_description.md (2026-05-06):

# Peeling Instrument — Design Specification

## Hardware

- **MCU:** Raspberry Pi Pico (RP2040) on Pimoroni Pico Explorer Base
- **Motor:** NEMA 17 stepper driven by DM542T driver
- **Display:** 1.54" 240×240 IPS ST7789
- **Buttons:** A (GPIO 12), B (GPIO 13), X (GPIO 14), Y (GPIO 15) — active-low, INPUT_PULLUP

### Button Physical Roles

| Button | Physical role |
|---|---|
| X | Limit switch — home end (simulated by button, wired to real microswitch) |
| A | Limit switch — far end (simulated by button, wired to real microswitch) |
| Y | User interface — START / STOP / increment setting |
| B | User interface — SETTINGS / HOME / cycle setting field |

---

## Unit Conversion

- **Step size:** 1 step = 0.9375 µm (motor displacement `d`)
- **Angle:** θ — user-set peeling angle in degrees (0–89°; 90° disallowed — cos(45°) ≠ 0 but cos(90°/2) approaches singularity at high angles; clamped to 89°)
- **Physical relation:** `d = 2 × L × cos(θ/2)` where `L` is true peeling displacement
- **Distance formula:** `L_µm = steps × 0.9375 / (2 × cos(θ/2))`
- **Speed formula:** `speed_µm_s = steps_per_s × 0.9375 / (2 × cos(θ/2))`
- **Inverse (µm → steps):** `steps = L_µm × 2 × cos(θ/2) / 0.9375`

---

## Coordinate Convention

- **Position 0** = microswitch X (home end)
- **Positive direction** = toward microswitch A (far end)
- **distance_XA** = calibrated total travel in steps (X→A); stored in flash

---

## State Machine

```
IDLE ──[Y, dist_XA > 0]──────────────► MOVING_TO_START
IDLE ──[Y, dist_XA == 0]─────────────► show "RUN CAL FIRST" (no movement)
IDLE ──[B, position == 0]────────────► SETTINGS
IDLE ──[B, position > 0]─────────────► HOMING

MOVING_TO_START ──[arrival]──────────► 100 ms pause ──► PEELING
MOVING_TO_START ──[Y]────────────────► IDLE (abort)
MOVING_TO_START ──[X triggered]──────► HOMING (safety)
MOVING_TO_START ──[A triggered]──────► IDLE (safety stop)

PEELING ──[Y]────────────────────────► IDLE (user stop)
PEELING ──[A triggered]──────────────► IDLE (end stop reached)
PEELING ──[X triggered]──────────────► IDLE (safety stop)

HOMING ──[X triggered]───────────────► IDLE (forceStop, setCurrentPosition(0), disable outputs)
HOMING ──[Y]─────────────────────────► IDLE (abort)

SETTINGS ──[B cycles fields]─────────► angle → speed → start_pos → CAL → (exit to IDLE, auto-save)
SETTINGS ──[Y short]─────────────────► increment current field
SETTINGS ──[Y hold 500 ms]───────────► fast-increment current field
SETTINGS ──[B long 500 ms]───────────► decrement current field
SETTINGS (on CAL field) ──[Y]────────► CAL sequence

CAL ──[homing complete]──────────────► run at 100 steps/s toward A
CAL ──[A triggered]──────────────────► record steps, save dist_XA, → IDLE
CAL ──[Y]────────────────────────────► abort, → IDLE (no save)
```

---

## Button Labels (dynamic per state)

| State | Y label | B label |
|---|---|---|
| IDLE (position == 0) | START | SET |
| IDLE (position > 0) | START | HOME |
| MOVING_TO_START | STOP | — |
| PEELING | STOP | — |
| HOMING | STOP | — |
| SETTINGS | + (or CAL on CAL field) | NEXT/- (short=cycle, long=decrement) |
| CAL | START/ABORT | — |

---

## Settings Fields (cycled by B)

| Field | Range | Increment (short Y) | Fast increment (hold Y) |
|---|---|---|---|
| Angle | 0–89° | 1° | — (small range) |
| Speed | 1–1000 µm/s | 1 µm/s | 10 µm/s |
| Start position | 0–dist_XA µm | 10 µm | 100 µm |
| CAL | — | triggers calibration | — |

Long-press B (500 ms) decrements the current field (angle/speed/start_pos).
Exiting CAL field (B cycles past it) returns to IDLE and auto-saves all settings.

---

## Motor Control Details

- **Homing speed:** 1067 steps/s (≈ 500 µm/s = 0.5 mm/s at θ=0°)
- **MOVING_TO_START speed:** 1067 steps/s (same as homing)
- **Peeling speed:** set by user (1–1000 µm/s), converted to steps/s
- **Transition at start position:** motor stops, 100 ms pause, then begins peeling
- **Acceleration:** `setAcceleration(2147483647)` — instant (no ramp)
- **ENA- timing:** `enableOutputs()` + 500 ms delay before first move (DM542T datasheet requirement); not repeated if motor is already enabled
- **Limit detection:** polling in `loop()` (reaction time ~1 ms at 100 steps/s → < 0.1 µm overshoot); MOVING / MOVING_TO_START / PEELING states use falling-edge + 2 ms debounce (`xNewPress`/`yNewPress`) so a switch already held from a previous home or cal run does not abort the next move before the motor escapes; HOMING / CAL_HOMING retain level detection

---

## Calibration Sequence (CAL)

1. Run homing sequence (motor runs negative at 100 steps/s until X triggers → set position = 0)
2. Run at 100 steps/s in positive direction toward A
3. When A triggers: record `dist_XA_steps = getCurrentPosition()`
4. Save `dist_XA_steps` to `Preferences`
5. Return to IDLE

If Y is pressed during CAL: abort immediately, do not save, return to IDLE.

---

## Persistent Storage (`Preferences` library)

| Key | Type | First-boot default |
|-----|---|---|
| `angle` | int | 30 |
| `speed_um` | float | 1.0 µm/s |
| `start_um` | float | 0.0 µm |
| `dist_xa` | int32 | 0 (not calibrated) |

All values saved when settings menu exits (B cycles past CAL back to IDLE).
`dist_xa` saved only after successful calibration run.

---

## Display Layout (240×240, content area y=34–206)

### Run screen

```
┌─[Y: START/STOP]──────────────[X: LIMIT]─┐
├──────────────────────────────────────────┤
│            PEELING           (size 2)    │  state
│  POS:   1234.5 µm            (size 2)    │  current position
│  SET:    93.8 µm/s           (size 1)    │  set speed
│  RUN:    93.8 µm/s           (size 1)    │  actual running speed
│  ANGLE:  30°                 (size 1)    │  tilt angle
│  TO END: 12.3 s              (size 1)    │  time to microswitch A (-- if not peeling)
│  PEEL T: 00:05               (size 1)    │  elapsed peel time (-- if not peeling)
│  [█████████████░░░░░░░░░░░]             │  progress bar (pos / dist_XA)
├──────────────────────────────────────────┤
└─[B: SET/HOME]────────────────[A: LIMIT]─┘
```

### Settings screen

Active field highlighted in yellow; others in cyan. Value shown large (size 2) with field name above it (size 1).

A hint line `"tap=NEXT  hold=-"` (textSize 1, cyan) is displayed at y=56 between the title and the first field. It disappears when the CAL field is active (long-press B has no effect there) and reappears on all other fields.

---

## Serial Interface (preserved)

**Commands (115200 baud):**
- `m<int32>` — move to absolute step position (clamped to [0, dist_XA])
- `s` — stop immediately
- `v<int>` — set speed in Hz (steps/s)

**JSON heartbeat (every 100 ms):**
```json
{"state":N,"position":N,"speed":N,"pos_um":F,"speed_um":F,"angle":N}
```

| Field | Description |
|---|---|
| `state` | 1=INIT, 2=MOVING, 3=WAITING |
| `position` | current position in steps |
| `speed` | current speed in steps/s |
| `pos_um` | current position in µm |
| `speed_um` | current speed in µm/s |
| `angle` | current angle in degrees |

---

## Safety Rules

1. If `dist_XA == 0` (never calibrated): Y (START) is blocked; display shows `RUN CAL FIRST`
2. Start position is clamped to `[0, dist_XA_µm]` at input time
3. Angle capped at 89° (prevents division by zero in µm↔steps conversion)
4. Both limit switches (X and A) stop the motor in any MOVING or PEELING state

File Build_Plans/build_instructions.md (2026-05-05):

# Peeling Instrument — Build Instructions

> **MAINS VOLTAGE HAZARD.** This instrument contains 220 V AC wiring. Work with the power cord unplugged at all times during assembly. Double-check every mains connection before first power-on.

---

## Tools Required

- Drill + step drill bit (for panel holes)
- File or deburring tool
- Crimping tool for bootlace ferrules (1.5 mm²)
- Soldering iron + solder
- Multimeter
- Small flat and Phillips screwdrivers
- Callipers (for panel layout)

---

## Step 1 — Verify Component Fit Before Any Drilling

Before cutting anything, dry-fit the three largest components inside the bare enclosure shell (Hammond 1455Q2202, interior ~215 × 120 × 48 mm):

| Component | Approx. dimensions |
|---|---|
| Mean Well LRS-75-24 PSU | 129 × 98 × 38 mm |
| DM542T stepper driver | 118 × 75 × 34 mm |
| Raspberry Pi Pico W | 51 × 21 × 4 mm |

A layout that works: PSU and DM542T side-by-side along the 215 mm axis, with the Pico W on a small perfboard between or above them. If they do not fit comfortably, consider mounting the PSU externally or using a larger enclosure before proceeding.

---

## Step 2 — Prepare the Front Panel

The front panel is a custom-printed aluminum panel from Front Panel Express (122 × 78 mm). Layout (left → right): buttons stacked left of the display, PWR rocker on the right.

```
|←7→|←14→|←5→|←57→|←5→|←22→|←12→|
     BTN-B       DISP        PWR
     BTN-Y
```

| Cutout | Size / shape | Notes |
|---|---|---|
| BTN-B | 14 × 14 mm square | Gateron KS-33 snap-in — top-left of display (GO / STOP / +) |
| BTN-Y | 14 × 14 mm square | Gateron KS-33 snap-in — bottom-left of display (SET / HOME / NEXT) |
| DISPLAY | ~57 × 43 mm rectangle | Adafruit 2.8" active area — measure module before ordering |
| PWR (rocker switch) | 22 × 30 mm rectangle | KCD3 footprint |

BTN-B centre: x = 14 mm, y = 20 mm. BTN-Y centre: x = 14 mm, y = 58 mm. Display centre: x = 54.5 mm, y = 39 mm. PWR centre: x = 99 mm, y = 39 mm.

> **Panel must be ordered at 1.5 mm aluminum** — this is the standard plate thickness Gateron KS-33 switch clips are designed to snap into. Measure the Adafruit 2.8" PCB before finalising the display cutout. Design and print the 3D display bezel after the module arrives.

Mount components into the front panel:
1. Snap the KCD3 rocker switch into its rectangular cutout.
2. Push each Gateron KS-33 switch through its 14×14 mm square hole from the rear until the clips snap onto the panel face. Fit the LP keycap onto the stem.
3. Fit the 3D-printed display bezel and Adafruit 2.0" module.

---

## Step 3 — Prepare the Rear Panel

Drill the following holes in the plastic rear end panel:

| Component | Hole size | Notes |
|---|---|---|
| Schurter 4301.1400 IEC inlet | 28 × 22 mm rectangle | Per Schurter datasheet |
| GX16-4 panel socket (motor) | 16 mm round | Aviation connector |
| Panel-mount micro-USB | Per part datasheet | Rear programming port |

Mount each component:
1. Press-fit / screw the Schurter IEC inlet. Insert a T1A 5×20 mm slow-blow fuse into the holder.
2. Thread the GX16-4 female socket through its hole and tighten the locking nut.
3. Mount the panel-mount micro-USB socket.

---

## Step 4 — Mains Wiring (IEC inlet → Rocker switch → PSU)

> Use 1.5 mm² wire (brown = L, blue = N, green-yellow = PE). Crimp a bootlace ferrule on every wire end before inserting into a screw terminal.

```
IEC C14 inlet (with fuse)
  L (fused) ──► Rocker switch IN ──► Rocker switch OUT ──► PSU L
  N         ──────────────────────────────────────────────► PSU N
  PE        ──────────────────────────────────────────────► PSU PE (earth)
```

- The Schurter 4301.1400 has the fuse inline on the L conductor.
- The rocker switch interrupts the L conductor only.
- Leave 30–40 mm of slack on each wire for routing.
- After wiring, tug each ferrule firmly to confirm it is seated.

---

## Step 5 — DC Power Chain (24 V and 5 V)

### 5a — PSU → DM542T (24 V)

Connect the Mean Well LRS-75-24 +V and -V output screw terminals directly to the DM542T VCC+ and VCC− power terminals using 0.5 mm² hookup wire.

### 5b — PSU → TSR 1-2450 → Pico W VSYS (5 V)

The TSR 1-2450 is a SIP-3 buck regulator (24 V in → 5 V out). Solder it to a small piece of perfboard:

```
PSU +24V ──► TSR pin 1 (Vin)
PSU  GND ──► TSR pin 2 (GND)
TSR pin 3 (Vout, 5V) ──► Pico W VSYS (pin 39)
PSU  GND ──► Pico W GND (pin 38)
```

The Pico W has an internal OR-diode between VSYS and the USB 5 V rail, so the panel-mount USB cable and the TSR 1-2450 can coexist safely.

---

## Step 6 — Stepper Driver Wiring (DM542T → Pico W)

The DM542T uses differential signal inputs (PUL+/−, DIR+/−, ENA+/−). Wire single-ended from the Pico W by tying the + side to 5 V and the − side to the GPIO:

| DM542T terminal | Connect to |
|---|---|
| ENA+ | Pico 5 V rail |
| ENA− | GPIO 3 |
| DIR+ | Pico 5 V rail |
| DIR− | GPIO 4 |
| PUL+ | Pico 5 V rail |
| PUL− | GPIO 5 |
| VCC+ | PSU +24 V |
| VCC− | PSU GND |
| A+, A−, B+, B− | GX16-4 panel socket (pins 1–4) |

> The Pico W GPIO outputs 3.3 V. With the + side tied to 5 V, the differential voltage seen by the DM542T is 5 V in the active state, which meets its input specification.

**Motor output (DM542T → GX16-4 panel socket):**

Solder four wires from the DM542T output terminals (A+, A−, B+, B−) to the GX16-4 female panel socket pins 1–4 respectively. Use the same pin mapping on the GX16-4 male cable-end plug.

---

## Step 7 — Display Wiring (Adafruit 2.8" ILI9341 → Pico W)

Connect using Dupont female-to-female jumper cables (no soldering):

| Adafruit #1770 pin | Pico W GPIO |
|---|---|
| VIN | 3.3 V (pin 36) |
| GND | GND |
| CLK | GPIO 18 |
| MOSI | GPIO 19 |
| CS | GPIO 17 |
| D/C | GPIO 16 |
| RST | not connected (firmware sets RST = −1) |
| LITE | GPIO 20 (backlight) |
| T_CLK, T_CS, T_DI, T_DO, T_IRQ | leave disconnected (touchscreen not used) |

Use the SPI0 bus (GPIO 18/19).

---

## Step 8 — Button Wiring

Both UI buttons are active-low with INPUT_PULLUP in firmware. The Gateron KS-33 has two signal pins and two SMD LED pins on its underside.

| Button | Signal GPIO | LED GPIO | Notes |
|---|---|---|---|
| BTN-B (top, keycap) | GPIO 12 | GPIO 6 (via transistor) | GO / STOP / + |
| BTN-Y (bottom, keycap) | GPIO 13 | GPIO 7 (via transistor) | SET / HOME / NEXT |

**Signal wiring:**
- Solder a short wire from one switch pin → GPIO (Dupont to Pico header)
- Solder a short wire from the other switch pin → GND
- The KS-33 is non-polar for signal; either pin is fine

**LED wiring (transistor circuit on perfboard):**

The KS-33 has two SMD LED pads underneath (+ and −). Drive each via a 2N2222:

```
Pico GPIO 6 ──► 1 kΩ ──► 2N2222 Base
                          2N2222 Collector ──► KS-33 BTN-B LED − pad
                          KS-33 BTN-B LED + pad ──► +5 V
                          2N2222 Emitter   ──► GND

Pico GPIO 7 ──► 1 kΩ ──► 2N2222 Base
                          2N2222 Collector ──► KS-33 BTN-Y LED − pad
                          KS-33 BTN-Y LED + pad ──► +5 V
                          2N2222 Emitter   ──► GND
```

Solder thin wires directly to the SMD LED pads on the underside of each switch.

> This LED control is not yet in the firmware. Add GPIO 6 and GPIO 7 outputs to the state machine (~10 lines) before testing button illumination.

---

## Step 9 — Programming Port

Connect a short micro-B to micro-B USB cable from the panel-mount micro-USB socket (rear panel) to the Pico W USB port. This allows firmware uploads via USB without opening the enclosure.

---

## Step 10 — Firmware Upload

With the enclosure open and the Pico W accessible:

```bash
# Compile
arduino-cli compile --fqbn rp2040:rp2040:rpipico:os=freertos \
  Peeling_Automation_Stepper_Control_Uno/

# Upload (replace port as needed)
arduino-cli upload --fqbn rp2040:rp2040:rpipico:os=freertos \
  --port /dev/ttyACM0 \
  Peeling_Automation_Stepper_Control_Uno/

# Monitor
arduino-cli monitor --port /dev/ttyACM0 --config baudrate=115200
```

Requires the **arduino-pico** core (Earle Philhower) and the **FastAccelStepper** library installed in Arduino CLI.

---

## Step 11 — First Power-On Test (bench, before closing)

Perform these checks with the enclosure open and the PSU connected but the stepper motor not yet plugged in.

1. **Mains safety check:** With power off, use a multimeter to verify continuity L→switch→PSU L, and that PE is connected to the PSU earth terminal.
2. **No-load voltage check:** Power on. Measure PSU output: should be 24 V ±1 V. Measure TSR 1-2450 output: should be 5 V ±0.25 V. Measure Pico W VSYS: should be ~5 V.
3. **Display check:** Display should light up and show the instrument UI within a few seconds of power-on.
4. **Button check:** Press BTN-B (GPIO 12) and BTN-Y (GPIO 13) and confirm the UI responds.
5. **Serial heartbeat:** Connect via USB, open monitor at 115200 baud, confirm `{"state":N,"position":N,"speed":N}` appears every 100 ms.
6. **Stepper check:** Plug in the motor cable. Send `v50` then `m100000` via serial. Motor should move; send `s` to stop.

---

## Step 12 — Close and Label

1. Orient the Pico W so its PCB antenna faces the plastic rear end panel for best WiFi reception.
2. Secure all internal components (PSU feet, DM542T DIN rail or screw mount, perfboard standoffs).
3. Route mains and DC wiring separately where possible.
4. Slide the enclosure body over the internal assembly and attach both end panels.
5. Attach the Front Panel Express aluminum panel to the front end cap.

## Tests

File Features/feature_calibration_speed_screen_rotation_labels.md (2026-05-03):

make the speed of the calibaration from 5 mm/s to 1 mm/s.

since the screen is rotated. take that in the consideration when labeling the buttons in the UI.

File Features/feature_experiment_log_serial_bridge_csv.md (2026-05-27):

# Feature: Experiment Log in the Serial Bridge

## Request

Add a logging function to the Python serial bridge so that when GO is pressed (i.e. the
instrument enters the PEELING state) the position-vs-time data is automatically recorded
along with all experiment metadata (angle, speed).  The web UI should show a live
indicator of the active log filename and save folder.

---

## Design Decisions (resolved)

| # | Topic | Decision |
|---|---|---|
| 1 | Log trigger — start | First heartbeat where `state == "PEELING"` → open new CSV file. No firmware change needed. |
| 2 | Log trigger — stop | First heartbeat where state *leaves* `"PEELING"` → write final row then close. |
| 3 | Re-trigger | If PEELING arrives while a file is already open, close the old file first then open a new one. |
| 4 | Disconnect safety | Serial disconnection also calls `_log_close()` so no data is lost mid-run. |
| 5 | File format | **CSV** (stdlib `csv` module — no new dependency). |
| 6 | File location | `serial_bridge/logs/` subdirectory (auto-created). |
| 7 | Filename | `peel_YYYYMMDD_HHMMSS_angNN_spdXpX.csv` — timestamp + key experiment params encoded in the name. |
| 8 | CSV columns | `timestamp` (ISO-8601 wall clock), `time_ms` (`peel_elapsed_ms` from firmware), `pos_um`, `speed_um_s` (actual), `state`. |
| 9 | Metadata | Angle and set-speed live in the filename only; no redundant header or extra columns. |
| 10 | Sample rate | Every heartbeat while in PEELING state ≈ 10 Hz (100 ms interval). |
| 11 | Console output | One line on open (`📄 Logging → …`), one line on close (`✓ Log closed — N rows written`). |
| 12 | UI indicator | Python bridge injects `log_info` into every WebSocket heartbeat. JS renders a `#log-status` div below the serial badge: filename in yellow + save folder in grey. Hidden when not logging. |
| 13 | PROGMEM sync | `serial_bridge/index.html` and the PROGMEM HTML block in the `.ino` kept identical. |

---

## CSV Layout

```
timestamp,time_ms,pos_um,speed_um_s,state
2026-05-27T14:30:22.143,0,500.00,1.02,PEELING
2026-05-27T14:30:22.243,100,501.02,1.03,PEELING
…
2026-05-27T14:30:45.843,23700,1987.44,0.00,IDLE
```

## Example Filename

```
logs/peel_20260527_143022_ang30_spd1p0.csv
```

## UI Indicator (serial bridge only)

While PEELING, below the "🔌 SERIAL connected" line:

```
📝 peel_20260527_143022_ang30_spd1p0.csv
→ logs
```

Filename shown in yellow; folder path in grey.  Element is empty (zero height) when not logging.
Hidden on WiFi path (ESP32 never sends `log_info`).

---

## Files Modified

| File | Change |
|---|---|
| `serial_bridge/serial_bridge.py` | `_log_open/row/close/dispatch` helpers; `log_info` injected into every broadcast; dispatch reordered before broadcast so status is accurate on the same frame |
| `serial_bridge/index.html` | `#log-status` CSS + div + JS in `render()` |
| `Peeling_Automation_Stepper_esp32/Peeling_Automation_Stepper_esp32.ino` | PROGMEM block kept in sync with `index.html` |

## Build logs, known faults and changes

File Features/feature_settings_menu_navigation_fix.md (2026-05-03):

when I press set. i get into the setting menu, but I immediately move down from the angle setting into the speed setting. I want to stay on the angle option before moving on to the next settting.

in the Cal option, why does it say press Y , it should say press cal button.

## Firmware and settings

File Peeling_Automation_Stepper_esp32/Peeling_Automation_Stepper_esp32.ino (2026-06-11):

// =============================================================================
// Project   : Peeling Thin Sheet Using Stepper Motor — ESP32 Controller
// File      : Peeling_Automation_Stepper_esp32.ino
// Author    : Lior Segev
// Version   : 4.3.0-esp32
// Date      : June 3, 2026
// =============================================================================
//
// OVERVIEW
// --------
// Firmware for a stepper-motor-driven thin-sheet peeling instrument.
// Controls a NEMA 17 via DM542T driver on a Wemos D1 R32 (ESP32)
// with a 2.8″ 240×320 ST7789 display and 4 external buttons.
//
// HARDWARE
// --------
//   • Wemos D1 R32 (ESP32 dual-core)
//   • NEMA 17 stepper motor (0.4 A rated)
//   • DM542T (V4.0) stepper driver — active-low ENA-
//       – t1: ENA→first PUL ≥ 200 ms (firmware uses 500 ms delay)
//       – t2: DIR stable before PUL ≥ 5 µs (setDirectionPin 40 µs)
//   • Microswitches: X = home end, Y = far end
//   • 2.8″ ST7789 240×320 TFT display (SPI/VSPI; RST → GPIO 2)
//   • 4 external push-buttons: A (start/stop), B (settings/home), X (increment/CAL), Y (decrement)
//
// PIN ASSIGNMENT
// ---------------
//   GPIO 26  — ENA+ (active-high; ENA- tied to GND)
//   GPIO 25  — DIR+ (DIR- tied to GND)
//   GPIO 27  — PUL+ (PUL- tied to GND)
//   [BUTTONS mode]
//   GPIO  4  — BTN_A  (UI: start/stop; settings: navigate up)
//   GPIO 33  — BTN_B  (UI: settings/home; settings: navigate down / exit+save)
//   GPIO 14  — BTN_X  (UI: settings: increment/CAL trigger; no-op outside settings)
//   GPIO 12  — BTN_Y  (UI: settings: decrement; no-op outside settings)
//   [ROTARY mode — bare EC11 encoder replaces the 4 buttons]
//   GPIO 14  — ENC_CLK  3-pin side pin 1 (was BTN_X); 100 nF cap to GND
//   GPIO  4  — ENC_DT   3-pin side pin 3 (was BTN_A); 100 nF cap to GND
//              GND      3-pin side pin 2 (common/middle)
//   GPIO 33  — ENC_SW   2-pin side, either pin  (was BTN_B); 100 nF cap to GND
//              GND      2-pin side, other pin
//   GPIO 12  — unused   (was BTN_Y)
//   GPIO 13  — LIMIT_SW_X (home/X limit switch, active-low)
//   GPIO 15  — LIMIT_SW_Y (far/Y limit switch, active-low, INPUT_PULLUP)
//   GPIO  2  — TFT_RST
//   GPIO 17  — TFT_DC
//   GPIO  5  — TFT_CS
//   GPIO 18  — SPI SCK  (VSPI default, shared with MAX31856)
//   GPIO 23  — SPI MOSI (VSPI default, shared with MAX31856)
//   GPIO 19  — SPI MISO (VSPI default; MAX31856 SDO)
//   GPIO 16  — TFT_BL
//   GPIO 21  — MAX31856 CS  (thermocouple amplifier)
//   GPIO 22  — MAX31856 DRDY (data-ready; LOW when conversion complete)
//   GPIO 32  — HEATER_PIN (LEDC auto-ch, 1 kHz PWM → N-channel MOSFET gate)
//
// UNIT CONVERSION
// ---------------
//   d = 2 × L × cos(θ/2)  →  L = d / (2 × cos(θ/2))
//   d (motor)    = steps × (1500 / steps_per_rev) µm
//   L (peel)     = steps × (1500 / steps_per_rev) / (2 × cos(θ/2))
//   speed_µm_s   = steps/s × (1500 / steps_per_rev) / (2 × cos(θ/2))
//
// STATE MACHINE
// -------------
//   IDLE → [A, dist_xa>0] → MOVING_TO_START → [arrival+100ms] → PEELING
//   IDLE → [A, dist_xa=0] → show warning "RUN CAL FIRST"
//   IDLE → [B, pos=0]     → SETTINGS  (B navigates down: speed→angle→start→steps→CAL→IDLE+save)
//   IDLE → [B, pos>0]     → HOMING
//   PEELING → [A or LIMIT_SW] → IDLE
//   HOMING  → [LIMIT_SW]      → IDLE (pos := 0)
//   SETTINGS/CAL field → [X] → CAL_HOMING → CAL_RUNNING → IDLE (saves dist_xa)
//   Any moving state → [A]   → IDLE (abort)
//   SETTINGS: A=up, B=down/exit+save, X=+/CAL, Y=-
//
// SERIAL INTERFACE  (115200 baud)
// --------------------------------
//   Commands: 'm'<int32> move to step pos, 's' stop, 'v'<int> set Hz,
//             'h'<0-255> set heater duty, 'b'<A|B|X|Y><1|0> virtual button press/release
//   Heartbeat every 100 ms: JSON with state, position, speed, temperatures, heater,
//     WiFi/WebSocket info, and all settings (see sendWsJson() for full field list)
// =============================================================================

#include <FastAccelStepper.h>
#include <Adafruit_GFX.h>
#include <Adafruit_ST7789.h>
#include <Adafruit_MAX31856.h>
#include <SPI.h>
#include <EEPROM.h>
#include <math.h>
#include <WiFi.h>
#include <AsyncTCP.h>
#include <ESPAsyncWebServer.h>
#include <ESPmDNS.h>
#include "wifi_credentials.h"

// ---- Input mode -------------------------------------------------------------
#define ROTARY  1   // Rotary encoder EC11 + push button
#define BUTTONS 2   // Four discrete push-buttons
#define INPUT_MODE  ROTARY   // change to BUTTONS for 4-button mode

// ---- Stepper driver pins ----------------------------------------------------
#define enablePinStepper  26
#define dirPinStepper     25
#define stepPinStepper    27

// ---- Display pins -----------------------------------------------------------
#define TFT_CS    5
#define TFT_DC   17
#define TFT_RST   2
#define TFT_BL   16

// ---- Button pins (active-low, INPUT_PULLUP) ---------------------------------
//   Used in BUTTONS mode for physical input.
//   In ROTARY mode these GPIOs are reassigned to the encoder (see below);
//   the IDX_A/B/X/Y indices are still used for the virtual-button (WiFi/serial) path.
#define BTN_A    4   // UI: start / stop; in settings: navigate up
#define BTN_B   33   // UI: settings / home; in settings: navigate down / exit+save
#define BTN_X   14   // UI: in settings: increment (+) or trigger CAL; no-op outside settings
#define BTN_Y   12   // UI: in settings: decrement (−); no-op outside settings  GPIO12: strapping pin — WROOM pull-down holds it LOW at boot (safe)

// ---- Rotary encoder EC11 pins (ROTARY mode only) ----------------------------
//   Bare 5-pin metal EC11. Reuses button GPIOs; GPIO 12 (was BTN_Y) left unused.
//   3-pin side (encoder): [CLK]-[GND]-[DT]   2-pin side (button): [SW]-[SW]
//   VCC not needed — INPUT_PULLUP (~45 kΩ) provides pull-up; encoder shorts to GND.
//   Hardware debounce: 100 nF ceramic cap from each signal pin to GND (RC ≈ 4.5 ms).
#define ENC_CLK  14   // CLK encoder pin 1 → GPIO 14; encoder pin 2 (common) → GND
#define ENC_DT    4   // DT  encoder pin 3 → GPIO 4
#define ENC_SW   33   // SW  button pin 4 or 5 → GPIO 33; other button pin → GND
#define LIMIT_SW_X 13  // home/X limit switch (active-low, INPUT_PULLUP)
#define LIMIT_SW_Y 15  // far/Y  limit switch (active-low, INPUT_PULLUP)

// ---- MAX31856 thermocouple amplifier (VSPI shared with display) ---------------
#define MAX_CS    21
#define MAX_DRDY  22

// ---- Heater MOSFET (LEDC, 1 kHz, 8-bit) ------------------------------------
#define HEATER_PIN  32

// ---- Display geometry -------------------------------------------------------
#define SCREEN_W   320
#define SCREEN_H   240
#define X_OFF        0
#define LEFT_W     200   // stepper UI column width (px)
#define TCOL_X     201   // temperature bar column start (1 px gap = vertical divider)

// Temperature bar geometry (right column)
#define TBAR_X     209   // bar left edge (centered with size-2 label in right column)
#define TBAR_W      40   // bar width in px
#define TBAR_TOP    46   // top of bar = 120 °C
#define TBAR_BOT   220   // bottom of bar = 0 °C
#define TBAR_H     (TBAR_BOT - TBAR_TOP)   // 174 px

#define BTN_W       52
#define BTN_H       28
#define BTN_LEFT_X   3
#define BTN_RIGHT_X (LEFT_W - BTN_W - 3)   // = 145; both button pairs stay in left column
#define BTN_TOP_Y    3
#define BTN_BOT_Y   (SCREEN_H - BTN_H - 3)

#define DIV_TOP_Y   33
#define DIV_BOT_Y  207

// Content y positions (run screen)
#define STATE_Y    36   // textSize 2 (16 px) → ends 52
#define POS_Y      56   //                    → ends 72
#define SETSPD_Y   76   //                    → ends 92
#define RUNSPD_Y   96   //                    → ends 112
#define ANGLE_Y   116   //                    → ends 132
#define TOEND_Y   136   //                    → ends 152
#define PEELT_Y   156   //                    → ends 172
#define BAR_X       20
#define BAR_Y     178   // 12 px bar → ends 190; bottom divider at 207
#define BAR_W     168   // shortened to stay in left column (20 + 168 = 188 < 200)
#define BAR_H      12
// TEMP_Y removed — temperature is shown in the right-column bar

// ---- Physical constants -----------------------------------------------------
// 1 full motor revolution = 1.5 mm linear travel.
// Step size = 1500 / steps_per_rev µm  (runtime variable: microns_per_step).
// CAL speed targets ≈1 mm/s at motor; calSpeedHz() computes this dynamically.

// ---- FastAccelStepper -------------------------------------------------------
FastAccelStepperEngine engine = FastAccelStepperEngine();
FastAccelStepper       *stepper = NULL;

// ---- Display ----------------------------------------------------------------
Adafruit_ST7789 tft = Adafruit_ST7789(&SPI, TFT_CS, TFT_DC, TFT_RST);

// ---- Thermocouple -----------------------------------------------------------
Adafruit_MAX31856 thermo(MAX_CS);   // hardware VSPI; DRDY read via digitalRead(MAX_DRDY)
float         lastTempC      = NAN; // NAN until first valid reading
unsigned long lastTempReadMs = 0;   // millis() of last SPI read (rate-limit to one per ~130 ms)
unsigned long lastDrdyHighMs = 0;   // millis() when DRDY was last seen HIGH; init in setup()

// ---- Heater state -----------------------------------------------------------
uint8_t heaterDuty = 0;            // current LEDC duty (0–255); updated by 'h' serial command

// ---- Temperature controller state ------------------------------------------
float tempSetpoint       = 50.0f;  // target °C (0–120)
bool  tempControlActive  = false;  // PID loop enabled (control loop deferred to next step)
bool  waitForTemp        = false;  // hold peel until temp reaches setpoint
bool  tempCtrlAutoEnabled = false; // true when GO auto-enabled temp control (so we auto-disable on end)
float kp                 = 60.0f;  // proportional gain
float ki                 =  0.15f; // integral gain
float kd                 = 900.0f; // derivative gain

// ---- PID runtime state (reset on activation) --------------------------------
#define PID_BAND  4.0f             // °C — bang-bang outside, PID inside
float         pidIntegral      = 0.0f;
float         pidLastError     = 0.0f;
float         pidFilteredDeriv = 0.0f;
unsigned long lastPidRunMs     = 0;    // 0 = first tick, skip computation

enum TempField { TFIELD_BACK, TFIELD_SETPOINT, TFIELD_KP, TFIELD_KI, TFIELD_KD, TFIELD_STARTSTOP };

bool      inTempSubMenu    = false;
TempField tempField        = TFIELD_BACK;
int       prevTempFieldIdx = -1;   // -1 = first draw needed in temp sub-menu

// ---- Persistent storage -----------------------------------------------------
#define EEPROM_MAGIC  0x50454C36u   // "PEL6" — wait_for_temp setting added
#define EEPROM_ADDR   0
#define EEPROM_SIZE   128

struct SavedSettings {
  uint32_t magic;
  int      angle_deg;
  float    speed_um_s;
  float    start_pos_um;
  int32_t  dist_xa_steps;
  float    tempSetpoint;
  float    kp;
  float    ki;
  float    kd;
  bool     tempControlActive;
  bool     waitForTemp;
};

// ---- Application state ------------------------------------------------------
enum AppState {
  IDLE,
  MOVING,            // serial-commanded move (no auto-peel)
  MOVING_TO_START,   // button-triggered: moves to start_pos, then auto-peels
  WAITING_FOR_TEMP,  // motor at start pos, waiting for temperature to reach setpoint
  PEELING,
  HOMING,
  SETTINGS,
  CAL_HOMING,
  CAL_RUNNING
};
AppState appState = IDLE;

enum SettingsField { FIELD_SPEED, FIELD_ANGLE, FIELD_START, FIELD_CAL, FIELD_TEMP, FIELD_WAIT_TEMP, FIELD_EXIT };
SettingsField settingsField = FIELD_SPEED;

// ---- User-configurable values -----------------------------------------------
const int steps_per_rev  = 25600;      // fixed — matches DM542T DIP switches; not user-adjustable
float   microns_per_step = 1500.0f / steps_per_rev;  // 0.05859375 µm/step
int     angle_deg      = 30;
float   speed_um_s     = 1.0f;
float   start_pos_um   = 0.0f;
int32_t dist_xa_steps  = 0;          // calibrated X→A distance in steps (0 = uncalibrated)

// ---- Motor state ------------------------------------------------------------
bool motorEnabled = false;

// ---- Peel sequencing --------------------------------------------------------
unsigned long startPeelAt   = 0;   // millis() target for MOVING_TO_START→PEELING (0=not armed)
unsigned long peel_start_ms = 0;

// ---- Button tracking --------------------------------------------------------
#define IDX_A 0
#define IDX_B 1
#define IDX_X 2
#define IDX_Y 3

bool          btnDown[4]      = {};
unsigned long btnPressAt[4]   = {};
bool          btnLongFired[4] = {};
unsigned long btnRepeatAt[4]  = {};

const unsigned long LONG_PRESS_MS = 500;
const unsigned long REPEAT_MS     = 100;
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
void loop() {
  unsigned long now = millis();

  // ---- Non-blocking WiFi / web server start ------------------------------------
  static bool webServerRegistered = false;
  static wl_status_t prevWifiStatus = WL_IDLE_STATUS;
  wl_status_t wifiStatus = WiFi.status();

  if (wifiStatus != prevWifiStatus) {
    if (wifiStatus == WL_CONNECTED) {
      String ip = WiFi.localIP().toString();
      snprintf(wifiIpStr, sizeof(wifiIpStr), "WiFi: %s", ip.c_str());
      MDNS.begin("peeling");
      if (!webServerRegistered) {
        ws.onEvent(onWsEvent);
        webServer.addHandler(&ws);
        webServer.on("/", HTTP_GET, [](AsyncWebServerRequest *req){
          req->send_P(200, "text/html", HTML_PAGE);
        });
        webServer.begin();
        webServerRegistered = true;
      }
      serverStarted = true;
    } else if (prevWifiStatus == WL_CONNECTED) {
      snprintf(wifiIpStr, sizeof(wifiIpStr), "WiFi: reconnecting");
    }
    prevWifiStatus = wifiStatus;
  }

  if (!serverStarted && millis() - wifiStartMs > 10000) {
    serverStarted = true;  // give up — run offline
    snprintf(wifiIpStr, sizeof(wifiIpStr), "WiFi: offline");
  }

  // ---- Virtual button snapshot (used by both input modes) ---------------------
  bool virtDown[4];
  portENTER_CRITICAL(&wsMux);
  for (int i = 0; i < 4; i++) virtDown[i] = virtualBtn[i];
  portEXIT_CRITICAL(&wsMux);

#if INPUT_MODE == ROTARY
  // ---- Rotary encoder CLK debounce + direction detection ----------------------
  bool clkRaw = (digitalRead(ENC_CLK) == LOW);
  if (clkRaw != encClkPrev) {
    encClkStableAt = now;
    encClkPrev     = clkRaw;
  }
  if ((now - encClkStableAt) >= ENC_DEBOUNCE_MS && clkRaw != encClkStable) {
    bool falling = clkRaw && !encClkStable;  // HIGH→LOW = falling edge (pulse start)
    encClkStable = clkRaw;
    if (falling) {
      int dir = (digitalRead(ENC_DT) == HIGH) ? +1 : -1;
      onRotaryStep(dir);
      updateButtons();
      sendWsJson();
    }
  }

  // ---- Rotary SW push button (press event only; no long-press) ----------------
  bool swRaw = (digitalRead(ENC_SW) == LOW);
  bool encBtnChanged = false;
  if (swRaw && !encSwDown) {
    encSwDown    = true;
    encSwPressAt = now;
    onRotaryPush();
    encBtnChanged = true;
  } else if (!swRaw && encSwDown) {
    encSwDown     = false;
    encBtnChanged = true;
  }
  if (encBtnChanged) {
    updateButtons();
    sendWsJson();
  }

  // ---- Virtual buttons (WiFi / serial bridge) still active in ROTARY mode ----
  {
    bool vBtnChanged = false;
    for (int i = 0; i < 4; i++) {
      if (virtDown[i] && !btnDown[i]) {
        btnDown[i]      = true;
        btnPressAt[i]   = now;
        btnLongFired[i] = false;
        btnRepeatAt[i]  = now + LONG_PRESS_MS;
        onButtonPress(i);
        vBtnChanged = true;
      } else if (!virtDown[i] && btnDown[i]) {
        btnDown[i] = false;
        onButtonRelease(i);
        vBtnChanged = true;
      }
    }
    if (vBtnChanged) {
      updateButtons();
      sendWsJson();
    }
  }

#else
  // ---- Physical 4-button polling ----------------------------------------------
  bool curDown[4] = {
    !digitalRead(BTN_A) || virtDown[IDX_A],
    !digitalRead(BTN_B) || virtDown[IDX_B],
    !digitalRead(BTN_X) || virtDown[IDX_X],
    !digitalRead(BTN_Y) || virtDown[IDX_Y]
  };

  bool btnChanged = false;
  for (int i = 0; i < 4; i++) {
    if (curDown[i] && !btnDown[i]) {
      btnDown[i]      = true;
      btnPressAt[i]   = now;
      btnLongFired[i] = false;
      btnRepeatAt[i]  = now + LONG_PRESS_MS;
      onButtonPress(i);
      btnChanged = true;
    } else if (!curDown[i] && btnDown[i]) {
      btnDown[i] = false;
      onButtonRelease(i);
      btnChanged = true;
    } else if (curDown[i] && btnDown[i]) {
      if (!btnLongFired[i] && now >= btnPressAt[i] + LONG_PRESS_MS) {
        btnLongFired[i] = true;
        btnRepeatAt[i]  = now + REPEAT_MS;
        onButtonLong(i);
        btnChanged = true;
      } else if (btnLongFired[i] && now >= btnRepeatAt[i]) {
        btnRepeatAt[i] = now + REPEAT_MS;
        onButtonRepeat(i);
        btnChanged = true;
      }
    }
  }
  if (btnChanged) {
    updateButtons();
    sendWsJson();
  }
#endif

  // ---- Limit switch polling ---------------------------------------------------
  bool curLimX = !digitalRead(LIMIT_SW_X);
  bool curLimY = !digitalRead(LIMIT_SW_Y);

  // Edge + debounce for MOVING safety abort: a switch may already be pressed when
  // a new move is commanded (e.g. right after homing), so level-only detection
  // would abort the move before the motor escapes the switch.
  if  (curLimX && !limitXPrev) limitXStableAt = now;
  else if (!curLimX)            limitXStableAt = 0;
  if  (curLimY && !limitYPrev) limitYStableAt = now;
  else if (!curLimY)            limitYStableAt = 0;
  bool xNewPress = curLimX && limitXStableAt > 0 && (now - limitXStableAt) >= LIMIT_DEBOUNCE_MS;
  bool yNewPress = curLimY && limitYStableAt > 0 && (now - limitYStableAt) >= LIMIT_DEBOUNCE_MS;
  if (xNewPress) limitXStableAt = 0;   // consume: fire once per press
  if (yNewPress) limitYStableAt = 0;
  limitXPrev = curLimX;
  limitYPrev = curLimY;

  if (appState == HOMING || appState == CAL_HOMING) {
    if (curLimX) {                              // home-end switch triggered
      stepper->forceStop();
      while (stepper->isRunning()) {}           // wait for PIO to flush buffered steps
      stepper->setCurrentPosition(0);
      if (appState == CAL_HOMING) {
        stepper->setSpeedInHz(calSpeedHz());
        stepper->runForward();
        limitYStableAt = 0;   // discard any Y noise accumulated during homing
        limitYPrev     = false;
        appState = CAL_RUNNING;
      } else {
        disableMotor();
        appState = IDLE;
      }
      updateButtons();
    }
  } else if (appState == CAL_RUNNING) {
    if (yNewPress) {                            // far-end switch (GPIO 15): edge+debounce guards against motor-startup transients
      dist_xa_steps = stepper->getCurrentPosition();
      stepper->forceStop();
      disableMotor();
      saveCalibration();
      appState = IDLE;
      updateButtons();
    }
  } else if (appState == MOVING || appState == MOVING_TO_START || appState == WAITING_FOR_TEMP || appState == PEELING) {
    if (xNewPress || yNewPress) {               // new contact only — not a stale press
      abortAndIdle();
      updateButtons();
    }
  }

  // ---- Serial command parser ---------------------------------------------------
  if (Serial.available() > 0) {
    char cmd = Serial.read();
    switch (cmd) {
      case 's':
        abortAndIdle();
        updateButtons();
        break;
      case 'v': {
        int32_t hz = Serial.parseInt();
        if (hz > 0) stepper->setSpeedInHz(hz);
        break;
      }
      case 'm': {
        int32_t pos = Serial.parseInt();
        int32_t maxPos = dist_xa_steps > 0 ? dist_xa_steps : 478085;
        pos = constrain(pos, (int32_t)0, maxPos);
        appState = MOVING;
        enableMotor();
        stepper->setSpeedInHz(100);
        stepper->moveTo(pos);
        updateButtons();
        break;
      }
      case 'h': {
        // h<duty>  — set heater duty 0–255 (e.g. h128 = 50%)
        int32_t duty = Serial.parseInt();
        if (tempControlActive) {
          Serial.println("{\"error\":\"heater manual override blocked — temp control is active\"}");
        } else {
          duty = constrain(duty, 0, 255);
          heaterDuty = (uint8_t)duty;
          ledcWrite(HEATER_PIN, heaterDuty);
          Serial.printf("{\"heater_duty\":%d,\"heater_freq_hz\":%u}\n",
                        (int)heaterDuty, (unsigned)ledcReadFreq(HEATER_PIN));
        }
        break;
      }
      case 'b': {
        // Virtual button inject from serial bridge: bA1=pressA  bA0=releaseA
        // Format: 'b' <letter A/B/X/Y> <'1'=press / '0'=release>
        unsigned long t0 = millis();
        while (Serial.available() < 2 && millis() - t0 < 10) { /* spin ≤10 ms */ }
        if (Serial.available() >= 2) {
          char letter = (char)Serial.read();
          char state  = (char)Serial.read();
          int  idx    = -1;
          if      (letter == 'A') idx = IDX_A;
          else if (letter == 'B') idx = IDX_B;
          else if (letter == 'X') idx = IDX_X;
          else if (letter == 'Y') idx = IDX_Y;
          if (idx >= 0) {
            bool pressed = (state == '1');
            portENTER_CRITICAL(&wsMux);
            virtualBtn[idx] = pressed;
            portEXIT_CRITICAL(&wsMux);
          }
        }
        break;
      }
    }
  }
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

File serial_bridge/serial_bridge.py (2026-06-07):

#!/usr/bin/env python3
"""
serial_bridge.py — Serial ↔ WebSocket bridge for the Peeling Thin-Sheet Controller.

Serves the web UI at http://localhost:8080 and bridges:
  ESP32 serial TX  →  browser WebSocket  (JSON heartbeat + injected "transport":"serial")
  browser WS click →  ESP32 serial TX    (bA1 / bA0 button-inject commands)

The ESP32 continues to serve the same UI over WiFi independently; serial and WiFi
can be active at the same time.

Experiment logging
  When the firmware enters the PEELING state a CSV file is automatically opened in
  logs/ (next to this script).  Each 100 ms heartbeat is written as one row.  The
  file is closed when the state leaves PEELING.

  Filename:  peel_YYYYMMDD_HHMMSS_angNN_spdXpX.csv  (decimal point → 'p')
  Columns:   timestamp, time_ms, pos_um, speed_um_s, state

Usage:
    python serial_bridge.py [port] [--http-port PORT]

    port          Serial port, e.g. /dev/ttyUSB0 or COM3.
                  If omitted the first CH340 USB-serial adapter is used
                  (VID 1A86 / PID 7523 — the chip on the Wemos D1 R32).

    --http-port   HTTP port for the web UI (default: 8080).

Requirements:
    pip install websockets pyserial
    (Python 3.8+)
"""

import argparse
import asyncio
import csv
import datetime
import json
import logging
import sys
import threading
from http.server import BaseHTTPRequestHandler, HTTPServer
from pathlib import Path
from typing import Optional, Set

try:
    import serial
    import serial.tools.list_ports
except ImportError:
    sys.exit("pyserial not installed.  Run:  pip install pyserial")

try:
    import websockets
except ImportError:
    sys.exit("websockets not installed.  Run:  pip install websockets")

# ── Fixed addresses ───────────────────────────────────────────────────────────
HTTP_HOST = "127.0.0.1"
WS_HOST   = "127.0.0.1"
WS_PORT   = 8082           # browser connects to ws://localhost:8082/ws

# CH340 USB-serial converter (Wemos D1 R32 / most cheap ESP32 dev boards)
CH340_VID = 0x1A86
CH340_PID = 0x7523

BAUD_RATE          = 115200
RECONNECT_INTERVAL = 2.0   # seconds between reconnect attempts

HTML_PATH = Path(__file__).parent / "index.html"

# ── Runtime globals (all asyncio-thread accesses except where noted) ──────────
_clients: Set           = set()   # active browser WebSocket connections
_latest:  Optional[str] = None    # last heartbeat JSON (sent to new clients on connect)
_ser:     Optional[serial.Serial] = None   # current open serial port (None = disconnected)
_ser_lock = threading.Lock()      # guards _ser for cross-thread safety

# ── Experiment log state ───────────────────────────────────────────────────────
LOG_DIR = Path(__file__).parent / "logs"
_log_file   = None          # open file object (None = not logging)
_log_writer = None          # csv.writer for _log_file
_log_rows   = 0             # rows written in current log
_prev_state = ""            # last seen state string (edge detection)

LOG_COLUMNS = ["timestamp", "time_ms", "pos_um", "speed_um_s", "state"]


def _log_open(obj: dict) -> None:
    """Open a new CSV log file for a peeling run."""
    global _log_file, _log_writer, _log_rows
    LOG_DIR.mkdir(parents=True, exist_ok=True)
    ts      = datetime.datetime.now().strftime("%Y%m%d_%H%M%S")
    ang     = int(obj.get("angle", 0))
    spd     = float(obj.get("speed_set",     0.0))
    tmp     = float(obj.get("temp_setpoint", 0.0))
    spd_str = f"{spd:.1f}".replace('.', 'p')   # e.g. 1.5 → "1p5" (no dots in stem)
    tmp_str = f"{tmp:.1f}".replace('.', 'p')
    fname   = LOG_DIR / f"peel_{ts}_ang{ang}_spd{spd_str}_tmp{tmp_str}.csv"
    _log_file   = open(fname, "w", newline="", encoding="utf-8")
    _log_writer = csv.writer(_log_file)
    _log_writer.writerow(LOG_COLUMNS)
    _log_rows   = 0
    print(f"📄 Logging → {fname}")


def _log_row(obj: dict) -> None:
    """Append one heartbeat row to the open log."""
    global _log_rows
    if _log_writer is None:
        return
    ts     = datetime.datetime.now().isoformat(timespec="milliseconds")
    row = [
        ts,
        obj.get("peel_elapsed_ms", 0),
        round(float(obj.get("pos_um",    0.0)), 2),
        round(float(obj.get("speed_um",  0.0)), 3),
        obj.get("state", ""),
    ]
    _log_writer.writerow(row)
    _log_rows += 1


def _log_close() -> None:
    """Flush and close the current log file."""
    global _log_file, _log_writer, _log_rows
    if _log_file is None:
        return
    _log_file.flush()
    _log_file.close()
    print(f"✓ Log closed — {_log_rows} rows written")
    _log_file   = None
    _log_writer = None
    _log_rows   = 0


def _log_dispatch(obj: dict) -> None:
    """
    Called for every parsed JSON heartbeat.
    Opens / appends / closes the log based on state transitions.
    """
    global _prev_state
    state = obj.get("state", "")

    if state == "PEELING":
        if _log_file is None:
            _log_open(obj)
        _log_row(obj)
    else:
        if _log_file is not None:
            # Write the final non-PEELING row so the transition is visible
            _log_row(obj)
            _log_close()

    _prev_state = state


# ─────────────────────────────────────────────────────────────────────────────
# HTTP server  — serves index.html from this directory
# Runs in a daemon thread so it never blocks the asyncio event loop.
# ─────────────────────────────────────────────────────────────────────────────
class _HttpHandler(BaseHTTPRequestHandler):
    def do_GET(self) -> None:
        if self.path in ('/', '/index.html'):
            body = HTML_PATH.read_bytes()
            self.send_response(200)
            self.send_header('Content-Type', 'text/html; charset=utf-8')
            self.send_header('Content-Length', str(len(body)))
            self.end_headers()
            self.wfile.write(body)
        else:
            self.send_response(404)
            self.end_headers()
            self.wfile.write(b'Not found\n')

    def log_message(self, *_args) -> None:
        pass   # suppress per-request log noise


def _start_http(http_port: int) -> None:
    """Blocking HTTP server — called in a daemon thread."""
    server = HTTPServer((HTTP_HOST, http_port), _HttpHandler)
    server.serve_forever()


# ─────────────────────────────────────────────────────────────────────────────
# WebSocket handler  — browser → Python
# Each browser tab gets one call to this coroutine.
# ─────────────────────────────────────────────────────────────────────────────
async def _ws_handler(websocket, path: str = '/ws') -> None:
    global _clients, _latest
    _clients.add(websocket)
    # Replay the most recent heartbeat so the UI is populated immediately.
    if _latest:
        try:
            await websocket.send(_latest)
        except Exception:
            pass
    try:
        async for raw in websocket:
            await _forward_to_serial(raw)
    except Exception:
        pass
    finally:
        _clients.discard(websocket)
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

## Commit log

2026-04-15 Update driver specifications and configuration in README and firmware for DM542T stepper driver
2026-04-15 Refactor stepper motor control to manually manage ENA- pin and improve initialization sequence
2026-04-16 Increase stepper motor acceleration to maximum for immediate response
2026-04-30 Update project details and hardware specifications for Raspberry Pi Pico integration
2026-05-03 Update stepper driver pin assignments for improved control
2026-05-03 complete redesign of the UI functionality
    [Peeling_Automation_Stepper_Control_Uno.ino]
2026-05-03 Update stepper speed setting to use CAL_SPEED_HZ constant for improved configurability
2026-05-03 Improve display update logic to prevent flicker by padding state string
    [Peeling_Automation_Stepper_Control_Uno.ino]
2026-05-03 Fix settings navigation to remain on angle option and update calibration prompt text
    [Peeling_Automation_Stepper_Control_Uno.ino]
2026-05-04 Fix display flicker by optimizing row updates and increase button text size for better visibility
    [Peeling_Automation_Stepper_Control_Uno.ino]
2026-05-04 Update unit conversion formulas for stepper motor distance and speed calculations
2026-05-04 Reorder setup sequence to initialize stepper before UI drawing for accurate position reading
2026-05-05 Update settings to allow WebSearch and WebFetch permissions; revise enclosure specifications and MPN in parts list
2026-05-05 Update actual parts list and add build instructions for Peeling Instrument
    - Updated display and UI button specifications in actual_parts_for_instrument.md.
    - Added detailed build instructions in build_instructions.md, covering assembly steps, wiring, and testing procedures.
    - Introduced new SVG files for the front and rear panels, detailing cutouts and dimensions.
2026-05-06 Fix limit switch detection logic to use falling-edge with debounce for safety abort
2026-05-06 Enhance B button functionality in SETTINGS: update label to "NEXT/-" and add hint for long-press action
2026-05-06 Implement B button long-press functionality and add steps per revolution parameter to UI
2026-05-11 Port firmware to Wemos D1 R32 (ESP32) on new esp32 branch
    Copies the Pico sketch to Peeling_Automation_Stepper_esp32/ and adapts it
    for ESP32: reassigns all GPIO pins to safe ESP32 GPIOs, replaces RP2040-only
    SPI.setRX/TX/SCK() with SPI.begin(18,19,23,-1) for VSPI, bumps EEPROM magic
    to PEL3, removes native-USB serial wait, and updates CLAUDE.md with the
    ESP32 build/upload commands.
    [Peeling_Automation_Stepper_esp32.ino]
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2026-05-11 esp32 replaced correctly the pico in functioning
    [Peeling_Automation_Stepper_esp32.ino]
2026-05-11 Add WiFi functionality and WebSocket support with HTML UI
    - Implemented WiFi connection in station mode with non-blocking boot.
    - Added WebSocket for real-time communication and JSON heartbeat updates.
    - Created a pixel-perfect HTML canvas UI that mirrors the physical display.
    - Included button press/release events for remote control of the device.
    - Updated required libraries and added design specifications for WiFi feature.
2026-05-13 Enhance WiFi stability and status reporting in setup and loop functions
    [Peeling_Automation_Stepper_esp32.ino]
2026-05-13 Update button pin assignments for microswitches and add GPIO usage notes to i2c pins
2026-05-14 Refactor button assignments and UI logic; remove microstep settings from configuration
2026-05-14 Update limit switch definitions and README for ESP32 compatibility
2026-05-25 Update comments to clarify hardware components and button functions
2026-05-27 Add documentation for future temperature control feature and GPIO adjustments
2026-05-27 Add serial bridge for Peeling Thin-Sheet Controller
    - Implemented `serial_bridge.py` to create a Serial ↔ WebSocket bridge.
    - Added `index.html` for the web UI interface.
    - Included `requirements.txt` for necessary Python packages: `websockets` and `pyserial`.
    - Created `upload_fs.py` to build and flash the LittleFS filesystem image to the ESP32.
2026-05-31 Refactor code structure for improved readability and maintainability
    [schematic_design.dxf]
2026-06-01 fix: update ST7789 display connection and adjust backlight initialization
    [Peeling_Automation_Stepper_esp32.ino]
2026-06-01 fix: correct display resolution in comments and update related documentation and fixed line seperator position
    [Peeling_Automation_Stepper_esp32.ino]
2026-06-03 feat: integrate MAX31856 thermocouple support and update button mappings in firmware
2026-06-03 feat: add temperature display to run screen with fault handling
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2026-06-04 feat: update heater control to include duty cycle in JSON output and logging
2026-06-07 feat: Implement Serial-Bridge Web UI for USB communication
    - Added a Python program to serve the same web UI over USB serial as currently available via WiFi.
    - Enabled parallel operation of WiFi WebSocket and serial bridge.
    - Introduced new serial commands for button press/release injection.
    - Updated ESP32 firmware to support new serial commands and maintain state machine parity with WiFi mode.
    - Created necessary files for the serial bridge including requirements and HTML source.
    - Implemented auto-reconnect for serial disconnection and improved user experience with transport indicators.
    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
2026-06-07 Enhance UI and functionality of the Peeling Controller
    - Increased canvas size and adjusted aspect ratio for better display.
    - Updated button layout and added new temperature settings fields.
    - Improved drawing functions for buttons, dividers, and temperature column.
    - Enhanced the settings screen to accommodate new temperature controls.
    - Adjusted WebSocket URL for local development.
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2026-06-07 feat: implement enhanced PID control logic with safety cutoffs and state management
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2026-06-07 feat: enhance logging functionality with dynamic log directory selection and temperature logging
2026-06-10 feat: add safety check before stopping motor and update speed ramp for smoother operation. bug fixes where motor didn't move when pressing home when waiting for temp
    [Peeling_Automation_Stepper_Control_Uno.ino, Peeling_Automation_Stepper_esp32.ino]
2026-06-10 feat: improve temperature control stability with enhanced state management for temperature status
    [Peeling_Automation_Stepper_esp32.ino]
2026-06-10 feat: increase heater MOSFET frequency to 1 kHz for improved performance and prevent timer stalls. Enhance JSON sending logic with client queue checks.
    [Peeling_Automation_Stepper_esp32.ino]
2026-06-10 fix: adjust settings hint rectangle height for improved display clarity
    [Peeling_Automation_Stepper_esp32.ino]
2026-06-11 Refactor input handling: Introduce rotary encoder support and remove WiFi feature documentation
    - Added support for rotary encoder EC11 with push button, allowing for navigation and value editing in settings.
    - Updated button handling logic to accommodate rotary encoder input mode.
    - Removed existing WiFi feature documentation as it was deemed unnecessary.
    - Added new feature documentation for rotary encoder, detailing hardware setup, compile-time switches, and behavior in both main and settings screens.
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
